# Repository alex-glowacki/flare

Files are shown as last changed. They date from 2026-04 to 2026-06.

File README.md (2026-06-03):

# FLARE
**Flight Lab for Avionics Research & Engineering**

A custom 450mm quadcopter with a DIY STM32H7-based flight controller and
ESP-NOW RC link. Built from scratch as a hands-on avionics and embedded
systems learning project.

---

## Project Status

| Phase | Goal | Status |
|---|---|---|
| 1 | STM32H7 bring-up — blink, UART, toolchain | ✅ Done |
| 2 | IMU bring-up — BMI323, sensor fusion | ✅ Done |
| 2.5 | Magnetometer — QMC5883P hard-iron calibration | ✅ Done |
| 3 | PID loop — stabilization, DSHOT motor output | ✅ Done |
| 4 | RC link — ESP-NOW, channel parsing, arming | ✅ Done |
| 4.5 | GPS — M100-5883 UBX binary parser, USART3 DMA | ✅ Done |
| 4.75  | SD card blackbox logger | ✅ Done |
| 5 | Remote firmware — sticks, OLED, switches | 🟡 In progress |
| 6 | Flight testing & PID tuning | 🟡 In progress |
| 7 | *(Future)* LiDAR mapping — RPLiDAR + Pi companion | 🔲 |

### Phase 6 — Flight Testing Detail

| Item | Status |
|---|---|
| First outdoor hover flight | ✅ Done (LOG000/LOG001) |
| IMU mounting offset calibration | ✅ Done — roll=+0.27°, pitch=−3.80°, bench-verified |
| Mag hard-iron calibration | ✅ Done — offset_x=−251.0, offset_y=+41.5 |
| SD blackbox logger operational | ✅ Done — LOG000–LOG008 captured |
| Yaw kd tuning — damping spin | ✅ Done — kd=0.05 confirmed (LOG001) |
| Yaw kp/output limit increase | ✅ Done — kp=1.2, out_limit=300 (LOG007) |
| Prop/motor direction verification | ✅ Done — all confirmed correct |
| Weak motor identification | ✅ Done — M1 (Front-Left, CCW) confirmed weaker than M3 via swap test |
| M1 motor replacement | 🔲 Pending — Readytosky 2212 920KV CCW needed |
| Software roll trim (interim) | 🔲 Pending — awaiting M1 swap back to original position |
| Stable hands-off hover | 🔲 Pending |
| ki_yaw = 0.01 | 🔲 Pending — after stable hover confirmed |

---

## Hardware

### Frame
- Custom PETG-CF printed, F450-class (450mm), self-modeled

### Flight Controller — FK723M1-ZGT6
- MCU: STM32H723ZGT6 (Cortex-M7, 192MHz)
- SPI1: PA5=SCK, PA6=MISO, PA7=MOSI
- I2C1: PB6=SCL, PB7=SDA
- CS (IMU): PB0
- INT1 (IMU): PB1
- USART1: PA9=TX, PA10=RX (debug / CP2102)
- USART2: PA2=TX, PA3=RX (ESP32 RC link)
- USART3: PB10=TX, PB11=RX (GPS)
- TIM4 DSHOT: PD12=M1, PD13=M2, PD14=M3, PD15=M4
- SD CS: PC0 (SPI1 shared with IMU)
- LED: PG7 (LED_USER)

### IMU — BMI323 (Arvian breakout, B0FG2ZFHNM)

| Wire color | Signal | Pin |
|---|---|-----|
| Orange | CSB | PB0 |
| Brown | SCX | PA5 |
| Blue | SDX | PA7 |
| Green | SDO | PA6 |
| Purple | INT1 | PB1 |
| White | VDD | 3V3 |
| Gray | GND | GND |

### GPS + Compass — HGLRC M100-5883

| M100-5883 Pin | FK723M1 Pin | Notes |
|---|---|---|
| 5V | PDB BEC 5V  | Do not use STM32 3.3V pin |
| GND | Common GND  | |
| TX | PB11 (USART3 RX) | GPS data → STM32 |
| RX | PB10 (USART3 TX) | Optional config commands |
| SDA | PB7 (I2C1 SDA) | QMC5883P compass |
| SCL | PB6 (I2C1 SCL) | QMC5883P compass |

- GPS chip: u-blox M10 (10th gen), 72 channels, GPS/GLONASS/BDS/Galileo/QZSS
- GPS protocol: UBX binary, NAV-PVT messages, 115200 baud, DMA ring buffer
- GPS fix confirmed indoors (8 satellites)
- Compass chip: QMC5883P, I2C address `0x2C`, chip ID `0x80`
- Hard-iron offsets: `offset_x = -251.0f`, `offset_y = 41.5f` (calibrated)
- Yaw stable at ~161–165° stationary

### ESCs — Readytosky 35A (×4)

| Motor | Position | Spin | Cap color | Pin  |
|---|---|---|---|---|
| M1 | Front-Left  | CCW  | Silver | PD12 |
| M2 | Front-Right | CW | Black | PD13 |
| M3 | Rear-Right  | CCW  | Silver | PD14 |
| M4 | Rear-Left | CW | Black | PD15 |

- Firmware: Bluejay (replaces stock BLHeli_S)
- Protocol: DSHOT300
- Props: 1045R on CCW motors (M1/M3), 1045L on CW motors (M2/M4)
- Demag Compensation: High (configured via BLHeliSuite + ATmega328P Nano)
- Config backed up: `config/esc_blheli_setup.ini`

> ⚠️ M1 (Front-Left, CCW, silver cap) is a known weak motor — produces less
> thrust than M3 at equivalent DSHOT values. Confirmed via motor swap test
> (LOG007/LOG008). Replacement Readytosky 2212 920KV CCW unit required.

### Power Distribution
- QWinOut PDB with built-in 5V and 12V BECs
- 3S LiPo with XT60
- 4S upgrade planned post stable-flight (verify PDB BEC supports up to 16.8V first)

### RC Link
- Nano ESP32 modules (ESP-NOW, quad-side and remote)
- Quad-side ESP32: **MAC `D4:E9:F4:E6:E9:90`**, GPIO17 (TX) → STM32 PA3 (USART2 RX)
- Remote ESP32: FrSky M7 Hall Sensor Gimbals (×2), 2-position toggle switches for arm/mode
- Shared GND between ESP32 and STM32

> ⚠️ Do not power the quad-side Nano ESP32 from the BEC 5V → VIN pin. The
> ESP32-S3 core requires 3.3V. Power from STM32 3.3V pin or a dedicated 3.3V
> regulator.

> ⚠️ Do not flash STM32 via ST-Link while the ESP32 shares the USB power rail.
> ST-Link reset glitches can corrupt ESP32 flash mid-write, changing the
> reported MAC address.

### FAA Remote ID
- Ruko R111S — hardware mount completed

### SD Card Blackbox Logger
- WWZMDiB micro-SD module, SPI1 shared with BMI323, CS=PC0
- FatFS, 5Hz write / 1Hz flush
- f_printf has no `%f` support — all floats scaled to integers permanently
- Column names encode scale factor (e.g. `roll_x100`, `lat_x1e6`)
- Last log: LOG008.CSV

### Remote Controller Hardware (Phase 5 — in progress)
- **Gimbals:** FrSky M7 Hall Sensor (×2) — analog, 4 axes total
- **OLED:** HiLetgo 2.42" SSD1309 128×64, SPI 7-pin
- **Switches:** 2-position toggle — arming (dedicated), mode angle/acro (dedicated)
- Pin assignments TBD pending wiring

### Debug / Programming
- ST-Link V2 clone (V2J37S7) — SWD, CLI only
- CP2102 USB-UART adapter — COM3, 115200 baud
  - CP2102 TX → PA10, RX → PA9, GND → GND, VCC unconnected

---

## Repository Structure

```
flare/
├── firmware/
│   ├── shared/                    # Shared headers (ESP32 + STM32)
│   │   └── flare_protocol.h       # RC packet definition, CRC-8/MAXIM
│   ├── fc/                        # STM32H7 flight controller firmware
│   │   ├── Core/
│   │   │   ├── Inc/
│   │   │   │   ├── main.h
│   │   │   │   ├── dshot.h        # DSHOT300 driver API
│   │   │   │   ├── imu_fusion.h   # Complementary filter API
│   │   │   │   ├── mag.h          # QMC5883P magnetometer driver API
│   │   │   │   ├── pid.h          # PID controller API
│   │   │   │   ├── flare.h        # Motor mixing, arming logic API
│   │   │   │   ├── rc.h           # USART2 RC receiver API
│   │   │   │   └── gps.h          # UBX binary GPS parser API
│   │   │   └── Src/
│   │   │       ├── main.c         # Boot sequence, 100Hz loop, UART output
│   │   │       ├── imu_fusion.c   # Complementary filter (roll, pitch, yaw)
│   │   │       ├── mag.c          # QMC5883P magnetometer driver
│   │   │       ├── dshot.c        # DSHOT300 direct DMA output
│   │   │       ├── pid.c          # PID controller
│   │   │       ├── flare.c        # Motor mixing, arming logic
│   │   │       ├── rc.c           # USART2 interrupt-driven RC receiver
│   │   │       ├── gps.c          # UBX NAV-PVT parser, USART3 DMA ring buffer
│   │   │       └── stm32h7xx_it.c # IRQ handlers (incl. DSHOT TC callback)
│   │   ├── cmake/stm32cubemx/     # CubeMX-generated CMake support
│   │   ├── CMakeLists.txt
│   │   └── build/Debug/           # Build output (gitignored)
│   ├── esp32_quad/                # ESP-NOW quad-side firmware (PlatformIO)
│   │   ├── src/main.cpp           # ESP-NOW RX → UART bridge to STM32 ✅ flashed
│   │   ├── extra_script.py        # SCons path injection for shared header
│   │   └── platformio.ini
│   └── esp32_remote/              # ESP-NOW remote firmware (PlatformIO)
│       ├── src/main.cpp           # 50Hz transmitter stub — pending wiring
│       ├── extra_script.py        # SCons path injection for shared header
│       └── platformio.ini
├── config/
│   └── esc_blheli_setup.ini       # BLHeli_S ESC configuration backup
└── docs/
    ├── README.md
    ├── architecture.md
    ├── hardware-notes.md
    └── session_summaries/         # Per-session progress logs
```

---

## Toolchain

| Tool | Version |
|---|---|
| arm-none-eabi-gcc | 15.2.1  |
| CMake | 4.3.1 |
| Ninja | 1.13.2  |
| STM32CubeProgrammer | v2.22.0 |
| VS Code + clangd | — |
| PlatformIO | — |

---

## Build & Flash

### STM32 (working directory: `firmware/fc`)

**Build:**
```powershell
cmake --build --preset Debug
```

**Flash:**
```powershell
& "C:\Program Files\STMicroelectronics\STM32Cube\STM32CubeProgrammer\bin\STM32_Programmer_CLI.exe" -c port=SWD freq=100 reset=HWrst -w build/Debug/fc.elf -rst
```

### ESP32 (working directory: `firmware/esp32_quad` or `firmware/esp32_remote`)

**Build:**
```powershell
C:\Users\alexg\.platformio\penv\Scripts\platformio.exe run --environment arduino_nano_esp32
```

**Flash** (double-tap RST first to enter DFU mode):
```powershell
C:\Users\alexg\.platformio\penv\Scripts\platformio.exe run --target upload --environment arduino_nano_esp32
```

**Serial monitor:**
```powershell
C:\Users\alexg\.platformio\penv\Scripts\platformio.exe device monitor --environment arduino_nano_esp32 --baud 115200
```

---

## Current PID Gains

| Axis  | kp  | ki  | kd | int_limit | out_limit |
|---|-----|-----|---|---|---|
| Roll  | 0.5 | 0.0 | 0.10 | 20.0 | 150.0 |
| Pitch | 0.5 | 0.0 | 0.10 | 20.0 | 150.0 |
| Yaw | 1.2 | 0.0 | 0.05 | 20.0 | 300.0 |

### Gain Tuning Decision Table

| Observation | Action |
|---|---|
| Yaw spin >500 °/s at hover throttle | Check motor torque balance — likely physical cause |
| Yaw drift ~1 °/s at hover | Add ki_yaw = 0.01 |
| Motors M1/M3 >> M2/M4 at hover | M1 weak — replace motor |
| Flip above ~43% throttle | Motor saturation + imbalance; do not push above 40% until M1 replaced |
| Roll/pitch oscillation after motor replacement | Re-evaluate kp; may need slight reduction |

---

## Magnetometer Notes

The QMC5883P on the HGLRC M100-5883 module is wired to I2C1 (PB6/PB7).

### Hard-iron calibration (completed)

```c
offset_x = -251.0f;
offset_y =   41.5f;
```

Applied in `main.c` before fusion. Yaw stable at ~161–165° stationary.

---

## RC Link — FLARE Protocol

### Packet format (`firmware/shared/flare_protocol.h`)

| Byte(s) | Field | Type | Notes |
|---|---|---|---|
| 0 | magic | uint8_t | `0xFA` — sync byte |
| 1–2 | throttle | uint16_t  | 1000–2000 (1000 = min) |
| 3–4 | roll | uint16_t  | 1000–2000 (1500 = center) |
| 5–6 | pitch | uint16_t  | 1000–2000 (1500 = center) |
| 7–8 | yaw | uint16_t  | 1000–2000 (1500 = center) |
| 9 | armed | uint8_t | 0 = disarmed, 1 = armed |
| 10 | mode | uint8_t | 0 = angle, 1 = acro |
| 11–12 | reserved | uint8_t[2]| Zero-padded, future use |
| 13 | checksum | uint8_t | XOR checksum over bytes [0–12] |

Total: **14 bytes**. Shared header used by both ESP32 and STM32 firmware.

### STM32 RC receiver (rc.c / rc.h)

- USART2, 115200 8N1, PA3 = RX
- Direct register RX: `SET_BIT(USART2->CR1, USART_CR1_RXNEIE_RXFNEIE)`
- Sync recovery: discards bytes until magic is seen
- XOR checksum validated on complete 14-byte frame
- `RC_GetPacket()` — returns new packet to main loop (clears flag)
- `RC_IsHealthy()` — returns 1 if packet received within `RC_TIMEOUT_MS` (250ms)
- USART2 IRQ priority: 8,0 (below DMA1_Stream0 at 0,0)

### ESP32 quad-side firmware (esp32_quad/src/main.cpp) ✅ flashed

- ESP-NOW receiver, Station mode
- MAC address: **`D4:E9:F4:E6:E9:90`** ← updated after reflash (flash corruption
  during ST-Link programming changed MAC from `D4:E9:F4:E8:10:74`)
- `on_packet_received()` callback: validates magic + length + checksum, forwards
  raw 14-byte packet over UART to STM32
- UART: GPIO17 (TX) → STM32 PA3, 115200 baud

### ESP32 remote-side firmware (esp32_remote/src/main.cpp) 🟡 built, pending wiring

- ESP-NOW transmitter targeting `D4:E9:F4:E6:E9:90`
- 100Hz transmit loop, ADC stick read, deadband, XOR checksum
- Pin assignments placeholders — update once hardware is wired
- Arming and mode via `INPUT_PULLUP` toggle switches

### Shared header path resolution (Windows PlatformIO)

Both ESP32 projects use `extra_script.py` (SCons pre-build hook) to inject
the absolute path to `firmware/shared/` into `CPPPATH`:

```python
shared_path = os.path.abspath(
    os.path.join(env["PROJECT_DIR"], "..", "shared")
)
env.Append(CPPPATH=[shared_path])
```

`platformio.ini` references it via `extra_scripts = pre:extra_script.py`.
Relative `build_flags = -I` paths do not resolve correctly on Windows.

---

## DSHOT300 Configuration

### Timing (@ 192MHz SYSCLK, TIM4 ARR = 639)

| Symbol | Value  | Meaning |
|---|---|---|
| Bit period | 3.33µs | 300 kbps |
| BIT_1 | 480 | 75% duty cycle — logic 1  |
| BIT_0 | 240 | 37.5% duty cycle — logic 0|
| Idle | 0 | 0% duty — idle-LOW (Bluejay) |

### Key implementation facts

- **No HAL DMA burst API** — `HAL_TIM_DMABurst_WriteStart` ignores NDTR on
  STM32H7 and runs continuously. Direct DMA register programming used instead.
- **TIM4->DCR:** DBA=13 (CCR1 offset), DBL=3 (4 transfers per burst)
- **Buffer:** `dshot_buf[17][4]` uint32_t at `0x24000000` (D1 AXI SRAM)
- **Idle-LOW:** `DSHOT_CCR_IDLE = 0` — required for Bluejay firmware
- **Bluejay CRC:** non-inverted: `(v ^ (v>>4) ^ (v>>8)) & 0x0F`
- **ESC keepalive:** `DSHOT_SendThrottle(0,0,0,0)` called every loop iteration
- **DMA1_Stream0 IRQ priority:** 0,0 (highest)

---

## Sensor Fusion

A complementary filter runs at 100Hz producing roll, pitch, and yaw in degrees.

### Algorithm

```
// Roll and pitch — accel reference (with mounting offsets applied)
roll_accel  = atan2(ay_g, az_g)  × (180/π) - IMU_ROLL_OFFSET
pitch_accel = atan2(-ax_g, az_g) × (180/π) - IMU_PITCH_OFFSET

// Gyro integration
roll_gyro  = roll_prev  + gx_dps × dt
pitch_gyro = pitch_prev + gy_dps × dt
yaw_gyro   = yaw_prev   + gz_dps × dt

// Complementary filter — roll and pitch
roll  = α × roll_gyro  + (1−α) × roll_accel
pitch = α × pitch_gyro + (1−α) × pitch_accel

// Yaw — gyro only until mag-fused yaw hold implemented
yaw = yaw_gyro   (drifts over time)
```

### Parameters

| Parameter | Value  | Notes |
|---|---|---|
| α (alpha) | 0.96 | Roll/pitch gyro weight |
| dt | 0.01s  | Matches 10ms loop tick |
| IMU_ROLL_OFFSET  | +0.27° | Bench-calibrated mounting offset |
| IMU_PITCH_OFFSET | −3.80° | Bench-calibrated mounting offset |
| ACC scale | `8.0 / 32768.0` g/LSB  | ±8g range |
| GYR scale | `2000.0 / 32768.0` dps/LSB | ±2000dps range |

---

## UART Serial Output Format

115200 baud, USART1 (CP2102 on COM3).

Boot messages:
```
[DSHOT] driver ready
[DSHOT] ESCs armed
[FLARE] boot ok
[IMU] WHO_AM_I    = 0x43 (expect 0x43)
[IMU] ACC default = 0x0028
[IMU] ACC write   = 0x4028 (expect 0x4028)
[IMU] GYR write   = 0x4048 (expect 0x4048)
[FUSION] complementary filter ready
[MAG] chip ID = 0x80
[MAG] QMC5883P ready
[FLARE] PID controller ready
[RC] init status=0 (0=OK)
[RC] USART2 receiver ready
[GPS] USART3 DMA receiver ready
[GPS] waiting for fix (may take 30-120s outdoors)...
[CAL] Hold still — levelling IMU (2s)...
[CAL] level offset: roll=X.XX  pitch=XX.XX
[IMU] starting 100Hz loop
```

100Hz data stream:
```
A:<ax> <ay> <az>  G:<gx> <gy> <gz>  R:<roll>  P:<pitch>  Y:<yaw>  RC:<OK|LOST>
```

1Hz GPS print:
```
[GPS] fix=<0|1> sats=<n> lat=<deg> lon=<deg> alt=<ft> spd=<mph>
```

---

## ST-Link V2 Clone Notes

Firmware: V2J37S7. Known limitations:
- GUI connection in STM32CubeProgrammer fails — use CLI only
- ITM SWO non-functional
- VS Code F5 flashing non-functional
- Always pass `freq=100 reset=HWrst` flags to CLI

**Memory read workaround** (when UART unavailable): promote variables to
`volatile` globals → find address with `arm-none-eabi-nm fc.elf | grep <symbol>`
→ read via STM32CubeProgrammer CLI `--upload` at the address.

---

## CubeMX Regeneration Warning

Regenerating code in CubeMX can:
- Wipe `#include` statements placed outside `USER CODE` blocks
- Introduce brace mismatches
- Move `/* USER CODE END WHILE */` outside the loop body
- Wipe MPU region config from `MPU_Config()` — always restore Region 1
  (AXI SRAM at `0x24000000`) after regen
- Wipe NVIC lines for USART2 — must be kept inside USER CODE blocks

Always inspect `main.c` after any CubeMX regeneration before building.

---

## Known Issues & Gotchas

- **SD/IMU SPI sharing:** SD writes on SPI1 can cause single-sample BMI323 accel
  dropouts. Mitigation: last-known-good accel guard in fusion loop.
- **f_printf float support:** FatFS `f_printf` has no `%f` — all floats scaled
  to integers permanently. Never attempt `%f` in log writes.
- **GPIO43/44 on Nano ESP32:** Must never be assigned to hardware UART — corrupts
  USB Serial/JTAG stack unrecoverably without chip erase.
- **ESC arming window:** DSHOT 0 frames must reach ESC within ~300ms of power-on.
  Arm immediately after `DSHOT_Init()`, before IMU init delays.
- **M1 motor weakness:** M1 (Front-Left, CCW) produces less thrust than M3 at
  equivalent DSHOT values. Causes persistent left roll bias under aerodynamic load.
  Replacement required before stable hover is achievable.

---

## Commit Convention

```
<type>(<scope>): <description>

Types:  feat, fix, tune, test, docs, refactor, chore
Scopes: fc/imu, fc/fusion, fc/mag, fc/pid, fc/dshot, fc/main, fc/rc, fc/gps,
        esp32/quad, esp32/remote, shared, docs, control
```

Examples:
```
feat(fc/gps): replace NEO-6M NMEA parser with UBX binary for M100-5883
fix(fc/imu): apply IMU mounting offset correction in complementary filter
tune(control): increase yaw kp and output limit for authority at hover
docs: update README for session 22 — flight testing progress
```

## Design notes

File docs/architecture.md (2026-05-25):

# FLARE — Architecture Overview

---

## System Block Diagram

```
[Hall Gimbals] ──► [ESP32 Remote]
                         │
                   ESP-NOW (2.4GHz)
                         │
                   [ESP32 Quad]
                         │
                   UART (115200)
                   GPIO17 → PA3
                         │
                  [STM32H723 FC]
                   ├── BMI323 IMU (SPI1)
                   ├── QMC5883L Mag (I2C1) ← onboard M100-5883, deferred
                   ├── DSHOT300 → ESC × 4
                   ├── M100-5883 GPS (USART3, UBX binary)
                   ├── SD Card Logger (SPI1 shared, planned)
                   └── Barometer (future)
```

---

## Component Responsibilities

| Component | Role |
|---|---|
| STM32H723ZGT6 | PID, sensor fusion, DSHOT motor output, RC packet parsing |
| BMI323 | 6-axis IMU (gyro + accel) over SPI1 |
| QMC5883L (M100-5883) | 3-axis magnetometer, yaw reference, over I2C1 — driver deferred  |
| HGLRC M100-5883 | GPS (u-blox M10, UBX NAV-PVT) + onboard QMC5883L compass |
| SD card module | SPI1 blackbox logger, CS on PC0 — planned Phase 5.5 |
| ESP32 (quad) | ESP-NOW receive → UART bridge to STM32 ✅ flashed & verified |
| ESP32 (remote) | Stick ADC read → ESP-NOW transmit, OLED display (Phase 5) |
| Readytosky 35A ESCs | Motor drive via DSHOT300, Bluejay firmware |

---

## Development Phases

| Phase | Goal | Status |
|---|---|---|
| 1 | STM32H7 bring-up — blink, UART, toolchain | ✅ Done |
| 2 | IMU bring-up — BMI323, sensor fusion | ✅ Done |
| 2.5 | Magnetometer — QMC5883P, yaw fusion | ✅ Done |
| 3 | PID loop — stabilization, DSHOT motor output | ✅ Done |
| 4 | RC link — ESP-NOW, channel parsing, arming | ✅ Done |
| 4.5 | GPS — M100-5883 UBX binary parser, USART3 DMA | ✅ Done |
| 5 | Remote firmware — sticks, OLED, switches | 🟡 In progress |
| 5.5 | SD card blackbox logger | 🟡 Planned |
| 6 | Flight testing & tuning | 🔲 |
| 7 | *(Future)* LiDAR mapping — RPLiDAR + Pi companion | 🔲 |

---

## Firmware Structure

```
firmware/
├── shared/                      # Headers shared between ESP32 and STM32
│   └── flare_protocol.h         # RC packet struct, XOR checksum, constants
├── fc/                          # STM32H723 flight controller
│   ├── Core/
│   │   ├── Inc/                 # Headers
│   │   │   ├── main.h
│   │   │   ├── dshot.h          # DSHOT300 driver API
│   │   │   ├── imu_fusion.h     # Complementary filter API
│   │   │   ├── mag.h            # QMC5883P driver API (retiring → QMC5883L)
│   │   │   ├── pid.h            # PID controller API
│   │   │   ├── flare.h          # Motor mixing, arming logic API
│   │   │   ├── rc.h             # USART2 RC receiver API
│   │   │   └── gps.h            # UBX binary GPS parser API
│   │   └── Src/
│   │       ├── main.c           # Boot sequence, 100Hz loop, UART output
│   │       ├── imu_fusion.c     # Complementary filter (roll, pitch, yaw)
│   │       ├── mag.c            # QMC5883P I2C driver (mag_ok=0 until replaced)
│   │       ├── dshot.c          # DSHOT300 direct DMA output (no HAL burst)
│   │       ├── pid.c            # PID controller
│   │       ├── flare.c          # Motor mixing, arming logic
│   │       ├── rc.c             # USART2 direct-register RC receiver
│   │       ├── gps.c            # UBX NAV-PVT parser, USART3 DMA ring buffer
│   │       ├── stm32h7xx_it.c   # IRQ handlers — DSHOT TC, USART2, USART3 DMA
│   │       ├── spi.c            # CubeMX SPI1 init
│   │       ├── i2c.c            # CubeMX I2C1 init
│   │       ├── usart.c          # CubeMX USART1 + USART2 + USART3 init
│   │       ├── gpio.c           # CubeMX GPIO init
│   │       └── ...
│   ├── cmake/stm32cubemx/       # CubeMX CMake integration
│   ├── CMakeLists.txt           # Includes firmware/shared via get_filename_component
│   ├── CMakePresets.json        # Debug preset — build/Debug/
│   ├── STM32H723XG_FLASH.ld    # Linker script — includes .AXI_SRAM section
│   ├── fc.ioc                   # CubeMX project file
│   └── .clangd                  # clangd config for VS Code IntelliSense
├── esp32_quad/                  # Quad-side ESP32 ✅ flashed & running
│   ├── src/main.cpp             # ESP-NOW RX → UART bridge to STM32
│   ├── extra_script.py          # SCons pre-build: injects firmware/shared into CPPPATH
│   └── platformio.ini
└── esp32_remote/                # Remote-side ESP32 🟡 built, pending wiring
    ├── src/main.cpp             # 100Hz ESP-NOW transmitter, stick/switch stubs
    ├── extra_script.py          # SCons pre-build: injects firmware/shared into CPPPATH
    └── platformio.ini
```

---

## FC Firmware Architecture (Phase 4.5 complete)

All flight controller application code lives in `firmware/fc/Core/Src/`.
Peripheral init (`spi.c`, `i2c.c`, `usart.c`, `gpio.c`) is CubeMX-generated
and must not be edited manually except inside `USER CODE` blocks.

**Key principle:** All user code must remain inside `/* USER CODE BEGIN */` /
`/* USER CODE END */` markers to survive CubeMX regeneration. Always inspect
`main.c` after regeneration — CubeMX can wipe the MPU config and the
`while(1)` closing brace.

### main.c Boot Sequence

```
MPU_Config()        — AXI SRAM non-cacheable (0x24000000, 512KB) for DMA buffers
MX_*_Init()         — CubeMX peripheral init (GPIO, DMA, UART1/2/3, SPI, TIM, I2C)
DSHOT_Init()        — configure DMA1_Stream0, set CCRs idle-LOW, start PWM
                      800 × 10ms = 8s of DSHOT 0 frames (Bluejay arm sequence)
BMI323_Init()       — SPI bring-up, feature engine, acc/gyr config
IMU_Fusion_Init()   — zero roll/pitch/yaw state
MAG_Init()          — I2C bring-up; sets mag_ok=0 if chip ID fails (expected
                      until QMC5883L driver replaces QMC5883P driver)
FLARE_Init()        — PID state, motor mixing init
RC_Init()           — arm USART2 RX via direct register write
GPS_Init()          — start USART3 DMA circular receive (512-byte ring buffer)
IMU calibration     — 200 samples × 10ms, average last 50 for level offsets

100Hz while loop:
  BMI323_ReadAccel / ReadGyro
  MAG_ReadHeading              — skipped if mag_ok == 0
  IMU_Fusion_Update            — complementary filter, all 3 axes
  GPS_Update()                 — scan DMA ring buffer, parse UBX NAV-PVT packets
  RC_GetPacket()               — consume validated RC packet if available
  if RC healthy and mode != SAFE:
    FLARE_Update               — PID + motor mixing
  else:
    FLARE disarmed, DSHOT 0 keepalive
  UART_Print                   — live telemetry including RC:OK/LOST
  every 100 loops (1s):
    [GPS] print — fix, sats, lat, lon, alt (ft), speed (mph)
    [DIAG] print — DMA send/tc counters
```

---

## FLARE RC Protocol

Defined in `firmware/shared/flare_protocol.h`.

### Packet Layout (14 bytes)

| Byte(s) | Field | Type | Notes |
|---|---|---|---|
| 0 | magic | uint8_t | `0xFA` |
| 1–2 | throttle | uint16_t | 1000–2000 |
| 3–4 | roll | uint16_t | 1000–2000, center 1500 |
| 5–6 | pitch | uint16_t | 1000–2000, center 1500 |
| 7–8 | yaw | uint16_t | 1000–2000, center 1500 |
| 9 | armed | uint8_t | 0 = disarmed, 1 = armed |
| 10 | mode | uint8_t | FLARE_MODE_* constants |
| 11–12 | reserved | uint8_t[2] | Zero-padded, reserved |
| 13 | checksum | uint8_t | XOR over bytes [0–12] |

### STM32 RC Receiver (rc.c)

- Direct register RX: `SET_BIT(USART2->CR1, USART_CR1_RXNEIE_RXFNEIE)`
- `USART2_IRQHandler` reads `USART2->RDR` directly, calls `RC_UART_RxCpltCallback()`
- Sync recovery: first byte must be `FLARE_PACKET_MAGIC` (`0xFA`)
- On full packet: validate magic + XOR checksum, copy to shadow buffer
- `RC_GetPacket()` — copies shadow buffer to caller, clears flag
- `RC_IsHealthy()` — returns 1 if last valid packet within `RC_TIMEOUT_MS (250)`

---

## GPS Driver (gps.c)

### Approach
Circular DMA receive into a 512-byte ring buffer in AXI SRAM (non-cacheable).
`GPS_Update()` is called each main loop iteration and walks new bytes from the
DMA write head through a UBX state machine. Complete, checksummed NAV-PVT
packets are parsed and used to update `GPS_Data_t`. No interrupts required
beyond DMA housekeeping.

### Protocol
UBX binary at 115200 baud, 10Hz. Single message type parsed:

| Message | Class | ID | Payload | Fields extracted |
|---|---|---|---|---|
| UBX-NAV-PVT | 0x01  | 0x07 | 92 bytes | fix_type, flags, numSV, lat, lon, hMSL, gSpeed, headMot |

### Checksum
Fletcher-8 over CLASS + ID + LEN + PAYLOAD (standard UBX). Packets with
invalid checksums are silently discarded and the state machine resets.

### Unit Conversions
- Latitude/longitude: raw × 1e-7 = decimal degrees
- Altitude: mm × 0.00328084 = feet MSL
- Speed: mm/s × 0.001 = m/s; m/s × 2.23694 = mph
- Heading: raw × 1e-5 = degrees true

### DMA Buffer Placement
```c
static uint8_t gps_dma_buf[512] __attribute__((section(".AXI_SRAM")));
```
Placed in RAM_D1 via the `.AXI_SRAM` linker section. The MPU non-cacheable
region at `0x24000000` ensures CPU reads are coherent with DMA writes.

---

## DSHOT300 Implementation

### Approach
Direct DMA register programming — HAL DMA burst API ignored NDTR on STM32H7.

### Buffer Layout
`dshot_buf[17][4]` — 17 rows × 4 motors, placed in AXI SRAM at `0x24000000`.
16 data rows (one bit per row) + 1 reset slot row (all zeros).

### Key Constants (@ 192MHz SYSCLK, ARR = 639)
| Symbol | Value | Meaning |
|---|---|---|
| `DSHOT_BIT_1` | 480 | 75% duty — logic 1 |
| `DSHOT_BIT_0` | 240 | 37.5% duty — logic 0 |
| `DSHOT_CCR_IDLE` | 0 | 0% duty — idle-LOW (Bluejay) |
| Bit period | 3.33µs | 300 kbps (DSHOT300) |

### Bluejay CRC
Non-inverted: `crc = (v ^ (v>>4) ^ (v>>8)) & 0x0F`
Standard DSHOT spec uses inverted CRC — Bluejay does not.

### IRQ Priorities
| Interrupt | Priority | Reason |
|---|---|---|
| DMA1_Stream0 (TC) | 0, 0 | Highest — idle-LOW restore is time-critical  |
| DMA1_Stream1 | 0, 0 | USART3 GPS DMA housekeeping |
| USART2 (RC RX) | 8, 0 | Must not preempt DSHOT TC handler |

---

## ESP32 Quad-Side Architecture ✅

### esp32_quad/src/main.cpp

```
setup():
  Serial.begin(115200)            — debug output
  Serial2.begin(115200, ...)      — UART bridge to STM32 (GPIO17 TX → PA3 RX)
  WiFi.mode(WIFI_STA), disconnect
  esp_now_init()
  esp_now_register_recv_cb(on_packet_received)

loop() at 1s:
  print rx_ok / rejected counters and last channel values

on_packet_received():
  validate magic + length + XOR checksum
  forward raw 14-byte packet over Serial2 to STM32
```

- MAC: `D4:E9:F4:E6:E9:90` (updated after flash corruption — was `D4:E9:F4:E8:10:74`)

---

## ESP32 Remote Firmware Architecture (Phase 5 — in progress)

### esp32_remote/src/main.cpp — 100Hz transmitter

```
setup():
  Serial.begin(115200)
  pinMode ARM_SWITCH, MODE_SWITCH → INPUT_PULLUP
  WiFi.mode(WIFI_STA), disconnect
  print own MAC address
  esp_now_init()
  esp_now_register_send_cb(on_packet_sent)
  esp_now_add_peer(kQuadMac)   ← D4:E9:F4:E6:E9:90

loop() at 100Hz:
  analogRead() × 4 axes → map_stick() → 1000–2000
  digitalRead() × 2 switches → armed / mode flags
  build FLARE_RC_Packet_t
  XOR checksum → pkt.checksum
  esp_now_send(kQuadMac, &pkt, 14)
```

### Pending Before Complete
- Wire M7 gimbals → assign GPIO ADC pins
- Wire arm + mode switches
- Measure per-axis ADC min/center/max
- Determine axis reversal per gimbal orientation
- Wire SSD1309 OLED (SPI) → add display driver

---

## SD Card Blackbox Logger (Phase 5.5 — planned)

### Approach
Share SPI1 with BMI323. Dedicated CS on PC0. Log telemetry string (same format
as UART output) to a `.txt` or `.csv` file on micro-SD each loop iteration or
at a configurable decimated rate.

### Key Constraints
- SD card SPI timing is much slower than BMI323 — ensure transactions never
  overlap (straightforward in single-threaded main loop)
- SD writes are blocking; consider write buffering if 100Hz loop timing is affected
- PC0 must be added as `GPIO_Output` (`SD_CS`) in CubeMX before firmware work

---

## Toolchain

| Tool | Version  | Purpose |
|---|---|---|
| STM32CubeMX | 6.17.0 | Peripheral config + code gen |
| arm-none-eabi-gcc | 15.2.1 | ARM cross-compiler |
| CMake | 4.3.1 | Build system |
| Ninja | 1.13.2 | Build backend |
| STM32CubeProgrammer | v2.22.0  | Flash + RAM read via ST-Link |
| VS Code + clangd | — | Editor + IntelliSense |
| PlatformIO | — | ESP32 build + flash |

### Build & Flash

```powershell
# STM32 — build (from firmware/fc/)
cmake --build --preset Debug

# STM32 — clean build
cmake --build --preset Debug --clean-first

# STM32 — flash
& "C:\Program Files\STMicroelectronics\STM32Cube\STM32CubeProgrammer\bin\STM32_Programmer_CLI.exe" `
  -c port=SWD freq=100 reset=HWrst -w build/Debug/fc.elf -rst

# STM32 — RAM read (for variable inspection without UART)
& "C:\Program Files\STMicroelectronics\STM32Cube\STM32CubeProgrammer\bin\STM32_Programmer_CLI.exe" `
  -c port=SWD freq=100 -r32 <address> <length>

# Find variable addresses
arm-none-eabi-nm build/Debug/fc.elf | Select-String "variable_name"

# ESP32 — build (from firmware/esp32_quad/ or esp32_remote/)
C:\Users\alexg\.platformio\penv\Scripts\platformio.exe run --environment arduino_nano_esp32

# ESP32 — flash (double-tap RST first)
C:\Users\alexg\.platformio\penv\Scripts\platformio.exe run --target upload --environment arduino_nano_esp32

# ESP32 — serial monitor
C:\Users\alexg\.platformio\penv\Scripts\platformio.exe device monitor --environment arduino_nano_esp32 --baud 115200
```

### CMake shared include path

```cmake
get_filename_component(SHARED_INC
    "${CMAKE_SOURCE_DIR}/../shared"
    ABSOLUTE
)
target_include_directories(${CMAKE_PROJECT_NAME} PRIVATE
    Core/Inc
    ${SHARED_INC}
)
```

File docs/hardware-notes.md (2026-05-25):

# FLARE — Hardware Notes

---

## STM32H723ZGT6 (FK723M1 board)

- Cortex-M7 @ 192MHz SYSCLK (HSI PLL: PLLM=4, PLLN=12, PLLP=1)
- 1MB Flash, 564KB RAM, 144-pin LQFP
- **Clone ST-Link V2 (V2J37S7):** GUI connection in CubeProgrammer fails — use
  CLI only with `freq=100 reset=HWrst` flags. ITM SWO non-functional.

### Pin Assignments

| Function | Pin | Notes |
|---|---|---|
| SPI1 SCK | PA5 | BMI323 + SD card (shared bus) |
| SPI1 MISO | PA6 | BMI323 + SD card (shared bus) |
| SPI1 MOSI | PA7 | BMI323 + SD card (shared bus) |
| IMU CS | PB0 | Active-low, manual GPIO |
| IMU INT1 | PB1 | Not yet used |
| SD CS | PC0 | Planned — GPIO output, to be added in CubeMX |
| I2C1 SCL | PB6 | QMC5883L compass (M100-5883, deferred) |
| I2C1 SDA | PB7 | QMC5883L compass (M100-5883, deferred) |
| USART1 TX | PA9 | CP2102 RX (debug) |
| USART1 RX | PA10 | CP2102 TX (debug) |
| USART2 TX | PA2 | ESP32 quad-side UART RX (unused in Phase 4)  |
| USART2 RX | PA3 | ESP32 quad-side UART TX |
| USART3 TX | PB10 | GPS M100-5883 RX (config, optional) |
| USART3 RX | PB11 | GPS M100-5883 TX |
| User LED | PG7 (LED_USER) | |
| TIM4 CH1 | PD12 | DSHOT M1 (Front-Left) |
| TIM4 CH2 | PD13 | DSHOT M2 (Front-Right) |
| TIM4 CH3 | PD14 | DSHOT M3 (Rear-Right) |
| TIM4 CH4 | PD15 | DSHOT M4 (Rear-Left) |

> **Not broken out (do not use):** PA13, PA14 (SWD), PC14, PC15 (oscillator),
> PH0, PH1 (oscillator).

### CubeMX SPI1 Configuration (confirmed working)

```c
hspi1.Init.Mode                    = SPI_MODE_MASTER;
hspi1.Init.Direction               = SPI_DIRECTION_2LINES;
hspi1.Init.DataSize                = SPI_DATASIZE_8BIT;
hspi1.Init.CLKPolarity             = SPI_POLARITY_LOW;
hspi1.Init.CLKPhase                = SPI_PHASE_1EDGE;
hspi1.Init.NSS                     = SPI_NSS_SOFT;
hspi1.Init.BaudRatePrescaler       = SPI_BAUDRATEPRESCALER_16;  /* 6 MHz */
hspi1.Init.FirstBit                = SPI_FIRSTBIT_MSB;
hspi1.Init.NSSPMode                = SPI_NSS_PULSE_DISABLE;
hspi1.Init.FifoThreshold           = SPI_FIFO_THRESHOLD_01DATA;
hspi1.Init.MasterKeepIOState       = SPI_MASTER_KEEP_IO_STATE_ENABLE;
hspi1.Init.MasterInterDataIdleness = SPI_MASTER_INTERDATA_IDLENESS_00CYCLE;
```

### CubeMX I2C1 Configuration (confirmed working)

- Speed Mode: Fast Mode
- Clock Speed: 400000 Hz (400 kHz)
- Pins: PB6 = SCL (AF4), PB7 = SDA (AF4)

### CubeMX USART1 Configuration (debug)

- 115200 baud, 8N1, TX/RX mode
- PA9 = TX (AF7), PA10 = RX (AF7)
- No interrupt — polling TX via `HAL_UART_Transmit(..., HAL_MAX_DELAY)`

### CubeMX USART2 Configuration (ESP32 RC link)

- 115200 baud, 8N1, TX/RX mode
- PA2 = TX (AF7), PA3 = RX (AF7)
- **NVIC interrupt enabled**, priority **8, 0**
- Direct register RX: `SET_BIT(USART2->CR1, USART_CR1_RXNEIE_RXFNEIE)` armed
  from `RC_Init()` — bypasses `HAL_UART_Receive_IT` which hangs on STM32H7
- `USART2_IRQHandler` in `stm32h7xx_it.c` reads `USART2->RDR` directly and
  calls `RC_UART_RxCpltCallback()`

### CubeMX USART3 Configuration (GPS)

- **115200 baud**, 8N1, TX/RX mode
- PB10 = TX (AF7), PB11 = RX (AF7)
- DMA: DMA1_Stream1, USART3_RX request, Peripheral→Memory, byte width,
  **Circular mode** — continuous ring buffer receive
- NVIC interrupt enabled (for HAL DMA housekeeping)
- `GPS_Init()` starts DMA via `HAL_UART_Receive_DMA(&huart3, buf, 512)`
- `GPS_Update()` polls DMA write head via NDTR each loop iteration

### CubeMX TIM4 Configuration (DSHOT300)

- Prescaler: 0 (no division)
- Counter Period (ARR): 639
- Clock Division: DIV1
- Auto-Reload Preload: Enabled
- PWM Mode 1 on CH1–CH4 (PD12–PD15, AF2)
- DMA: DMA1_Stream0, TIM4_UP request, Memory→Peripheral, word width, Normal mode
- `DSHOT_CCR_IDLE = 0` — outputs held idle-LOW between frames (Bluejay requirement)

### STM32H7 SPI Gotchas

- **NSSP Mode** must be disabled and **MasterKeepIOState** must be enabled —
  otherwise the peripheral pulses CS between bytes even with manual CS control.
- **3-byte transactions are unreliable.** The STM32H7 SPI peripheral drops the
  3rd byte on 3-byte transfers regardless of approach. Always use 4-byte
  transactions padded with a dummy byte.
- **RX FIFO does not drain on CS de-assert.** Call `SPI1_FlushRxFifo()`
  (disable + re-enable peripheral) between transactions to prevent stale data.
- **Soft reset mid-transaction** leaves the peripheral in an undefined state.
  Follow with `HAL_SPI_DeInit()` + `MX_SPI1_Init()` to recover cleanly.

### STM32H7 DMA / DSHOT Gotchas

- **`HAL_TIM_DMABurst_WriteStart` ignores NDTR** on STM32H7 HAL and runs
  continuously regardless of Normal mode setting. Do not use it for DSHOT.
  Use direct DMA register programming instead.
- **DSHOT idle-LOW required for Bluejay.** `DSHOT_CCR_IDLE` must be 0, not
  ARR+1. Bluejay's stricter state machine rejects all frames when idle is HIGH.
  BLHeli_S tolerates idle-HIGH but pulses/gallops; Bluejay produces silence.
- **CCR must be forced idle-LOW after each frame.** Set `CCR1–CCR4 = 0` in the
  DMA transfer-complete ISR to restore idle-LOW between frames.
- **Do not force-abort DMA mid-transfer.** `DSHOT_StartDMA()` must wait for the
  previous stream to be disabled (EN bit cleared by TC handler) before
  re-arming.
- **IRQ priority:** DMA1_Stream0 must be at higher priority than USART2.
  Use 0,0 for DMA1_Stream0 and 8,0 for USART2.

### STM32H7 UART Gotcha — HAL_UART_Receive_IT hangs

`HAL_UART_Receive_IT` hangs on STM32H7 HAL when called after peripheral init
in certain FIFO/lock states. Workaround for USART2 RC receiver:

1. Unlock handle: `__HAL_UNLOCK(&huart2)`
2. Clear error flags: `__HAL_UART_CLEAR_FLAG(...)`
3. Force state: `huart2.gState = HAL_UART_STATE_READY`
4. Arm RX directly: `SET_BIT(USART2->CR1, USART_CR1_RXNEIE_RXFNEIE)`
5. Handle in `USART2_IRQHandler` by reading `USART2->RDR` directly

### CubeMX Regeneration Gotchas

- **MPU_Config() gets wiped.** CubeMX regeneration replaces the custom
  MPU config with a default 4GB no-access region. The AXI SRAM non-cacheable
  region (Region 0, `0x24000000`, 512KB, TEX=1 C=0 B=0) required for DMA
  buffers must be manually restored after every regen.
- **USER CODE blocks:** All user code must be inside `/* USER CODE BEGIN */` /
  `/* USER CODE END */` markers. Includes, defines, and callbacks placed outside
  are silently wiped on regen.
- **`while(1)` closing brace** can be lost on regen — always verify `main.c`
  compiles cleanly after regeneration.

### Linker Script

File: `STM32H723XG_FLASH.ld`

A custom `.AXI_SRAM` output section was added to place DMA buffers in the
non-cacheable RAM_D1 region:

```ld
.AXI_SRAM (NOLOAD) :
{
  . = ALIGN(4);
  *(.AXI_SRAM)
  *(.AXI_SRAM*)
  . = ALIGN(4);
} >RAM_D1
```

Any buffer shared between CPU and DMA should use:
```c
__attribute__((section(".AXI_SRAM")))
```

---

## BMI323 IMU (Arvian Breakout Board — Amazon B0FG2ZFHNM)

- **Interface:** SPI (Mode 0, MSB first, up to 10 MHz — using 6 MHz)
- **VCC:** 3.3V — do NOT connect to 5V
- **CS:** Active-low, driven manually via GPIO

### Wiring (Arvian → FK723M1)

| Wire Color | Arvian Label | FK723M1 Pin |
|---|---|---|
| Orange | CSB | PB0 |
| Brown | SCX | PA5 (SCK) |
| Blue | SDX | PA7 (MOSI)  |
| Green | SDO | PA6 (MISO)  |
| Purple | INT1 | PB1 |
| White | VDD | 3V3 |
| Gray | GND | GND |

### SPI Protocol

**Read (4 bytes total):**
```
TX: [addr | 0x80]  [0x00 dummy]  [0x00]  [0x00]
RX: [ignored]      [ignored]     [LSB]   [MSB]
```

**Write (4 bytes total):**
```
TX: [addr & 0x7F]  [data_LSB]  [data_MSB]  [0x00 dummy]
```

Use `HAL_SPI_TransmitReceive` for both reads and writes — `HAL_SPI_Transmit`
truncates multi-byte writes on STM32H7.

### Confirmed Register Values

| Register | Address | Value Written | Expected | Meaning |
|---|---|---|---|---|
| WHO_AM_I | 0x00 | — | 0x43 | Chip ID |
| ACC_CONF | 0x20 | 0x4028 | 0x4028 | 100Hz, ±8g, cont. |
| GYR_CONF | 0x21 | 0x4048 | 0x4048 | 100Hz, ±2000dps, cont.|

---

## HGLRC M100-5883 GPS + Compass Module

Replaces both the GY-NEO6MV2 (NEO-6M) GPS and the GY-271 (QMC5883P) magnetometer.

### Specs

| Spec | Value |
|---|---|
| GPS chip | u-blox M10 (10th gen) |
| Channels | 72 |
| Constellations | GPS, GLONASS, BDS, Galileo, QZSS |
| Update rate | 10 Hz |
| Baud rate | 115200 (default) |
| Protocol | UBX binary |
| Compass chip | QMC5883L |
| Compass interface | I2C, address `0x0D` |
| Size / weight | 21×21×8 mm / 7.73 g |
| Power | 3.3–5V (power from 5V BEC — some units need ≥3.7V) |

### Wiring (M100-5883 → FK723M1)

| M100-5883 Pin | FK723M1 Pin | Notes |
|---|---|---|
| 5V | PDB BEC 5V rail  | Never from STM32 3.3V pin |
| GND | Common GND | |
| TX | PB11 (USART3 RX) | GPS data → STM32 |
| RX | PB10 (USART3 TX) | Optional config commands |
| SDA | PB7 (I2C1 SDA) | QMC5883L — leave unsoldered for now |
| SCL | PB6 (I2C1 SCL) | QMC5883L — leave unsoldered for now |

### UBX NAV-PVT Fields Used

| Offset | Field | Unit | Converted to |
|---|---|---|---|
| 20 | fixType  | — | fix_type (0–5) |
| 21 | flags | — | fix_valid (bit 0)  |
| 23 | numSV | count | satellites |
| 24 | lon | deg×1e-7 | longitude (float)  |
| 28 | lat | deg×1e-7 | latitude (float) |
| 36 | hMSL | mm | altitude_ft |
| 60 | gSpeed | mm/s | speed_ms, speed_mph|
| 64 | headMot  | deg×1e-5 | course_deg |

### GPS Driver Notes

- DMA buffer: 512 bytes in `.AXI_SRAM` (non-cacheable)
- Parser: UBX state machine in `gps.c`, no NMEA parsing
- Requires valid 3D fix (`fixType >= 3` AND `flags & 0x01`) before populating data
- Cold start: 30–120 seconds outdoors; will not fix indoors

### QMC5883L Compass (Deferred)

- I2C address: `0x0D`
- Different chip and register map from the retired QMC5883P (GY-271)
- Driver to be written once GPS is verified working and SDA/SCL are soldered
- Will replace `mag.c` (currently QMC5883P driver, returning `mag_ok=0`)

---

## Nano ESP32 (Quad-side) ✅ Flashed & Running

- **Role:** ESP-NOW receiver → UART bridge to STM32
- **MAC address: `D4:E9:F4:E6:E9:90`** ← current MAC after reflash
  - Previous MAC was `D4:E9:F4:E8:10:74` — changed after flash corruption
    caused by ST-Link reset glitching the shared USB rail during STM32 flash
- **UART wiring:**

| ESP32 Pin | Direction | STM32 Pin |
|---|---|---|
| GPIO17 / A0 (TX) | → | PA3 (USART2 RX) |
| GND | shared | GND |

- GPIO18 (RX) wired to PA2 (USART2 TX) but unused in Phase 4
- Boot output confirms MAC address, ESP-NOW ready, diagnostic loop

> ⚠️ **Power:** Do not feed BEC 5V into Nano VIN. The ESP32-S3 requires 3.3V.
> Power from STM32 3.3V pin or a dedicated 3.3V regulator. The Nano may appear
> powered via VIN (LED on) but ESP-NOW will not function correctly.

> ⚠️ **Flash corruption risk:** Do not flash STM32 via ST-Link while the
> ESP32 is powered from the shared USB rail. ST-Link reset can corrupt ESP32
> flash mid-write, which silently changes the reported MAC address. Always
> disconnect or power-cycle the ESP32 before ST-Link flashing.

### Windows DFU Flash Note

First flash on a new Windows machine requires installing the Nano ESP32 board
package through Arduino IDE once — this provisions the WinUSB DFU driver that
PlatformIO's `dfu-util` needs. After that initial install, PlatformIO uploads
work standalone without Arduino IDE.

To enter DFU mode: double-tap the RST button. The RGB LED changes to indicate
DFU mode. Then immediately run the PlatformIO upload command.

---

## Nano ESP32 (Remote-side) 🟡 Firmware Built — Pending Wiring

- **Role:** Read M7 hall sensor gimbals + switches → transmit FLARE_RC_Packet_t
  to quad ESP32 via ESP-NOW at 100Hz
- **Target peer MAC:** `D4:E9:F4:E6:E9:90` (hardcoded in firmware as `kQuadMac`)
- **Pin assignments:** TBD — update `firmware/esp32_remote/src/main.cpp` once wired

### Planned Hardware

| Component | Part | Notes |
|---|---|---|
| Gimbals | FrSky M7 Hall Sensor (×2) | Analog output, 4 axes, 0–3.3V  |
| OLED | HiLetgo 2.42" SSD1309 128×64 SPI | Use SPI 7-pin variant |
| Arm switch  | 2-position ON-ON toggle | INPUT_PULLUP, LOW = armed |
| Mode switch | 2-position ON-ON toggle | INPUT_PULLUP, LOW = acro |

### ADC Calibration (TBD after wiring)

```cpp
#define ADC_MIN      100    // measure at stick minimum
#define ADC_MAX      4000   // measure at stick maximum
#define ADC_DEADBAND 40     // raw counts either side of center
```

---

## SD Card Blackbox Logger (Planned — Phase 5.5)

- **Module:** Standard SPI micro-SD breakout, 3.3V (level-shifted)
- **Bus:** Shared SPI1 with BMI323 (PA5 SCK, PA6 MISO, PA7 MOSI)
- **CS:** PC0 — dedicated GPIO output (to be added in CubeMX)
- **Logs:** UART telemetry stream to `.txt` or `.csv` on SD card

### Wiring (SD module → FK723M1)

| SD Pin | FK723M1 Pin | Notes |
|---|---|---|
| VCC | 3.3V | |
| GND | Common GND  | |
| SCK | PA5 | Shared with BMI323  |
| MOSI | PA7 | Shared with BMI323  |
| MISO | PA6 | Shared with BMI323  |
| CS | PC0 | Dedicated |

### CubeMX Changes Required

1. Add `PC0` as `GPIO_Output`, label `SD_CS`
2. No changes to SPI1 — configuration unchanged
3. Regenerate and audit `main.c` closing brace as always

---

## ESCs — Readytosky 35A BLHeli_S + Bluejay Firmware

- Signal wire: White
- Ground wire: Black
- **Firmware: Bluejay** (replaces stock BLHeli_S)
- Motor mapping (X-frame convention):

| Motor | Position | Spin | DSHOT Pin |
|---|---|---|---|
| M1 | Front-Left  | CCW  | PD12 |
| M2 | Front-Right | CW | PD13 |
| M3 | Rear-Right  | CCW  | PD14 |
| M4 | Rear-Left | CW | PD15 |

### Bluejay-Specific Notes

- **CRC is non-inverted:** `(v ^ v>>4 ^ v>>8) & 0xF` — opposite of the
  published DSHOT spec (`~(v ^ v>>4 ^ v>>8) & 0xF`). FLARE firmware uses
  non-inverted CRC to match Bluejay.
- **Idle state must be LOW.** Bluejay's stricter frame sync rejects all frames
  if the signal idles HIGH between frames. `DSHOT_CCR_IDLE = 0`.
- **Telemetry bit:** kept at 0 — bidirectional DSHOT not enabled.
- **DSHOT throttle range:** 48 (minimum) to 2047 (maximum). Values 1–47 are
  reserved special commands. 0 = disarm/stop.

### BLHeliSuite 4-Way Interface Setup

- Arduino Nano (ATmega328P) flashed with 4-way interface firmware
- **Baud: 115200** (default does not work — must select 115200 explicitly)
- LGT8F328P clones fail the 4-way-if handshake — must use genuine ATmega328P
- Nano COM port: COM11
- FC/debug COM port: COM3 (CP2102)

---

## CP2102 USB-UART Adapter

| CP2102 | FK723M1 |
|---|---|
| TX | PA10 (USART1 RX) |
| RX | PA9  (USART1 TX) |
| GND | GND |
| VCC | unconnected |

- COM port: COM3
- Baud: 115200 8N1

> ⚠️ Do not connect an explicit GND wire from CP2102 to STM32 if it could land
> on the RESET pin — shared ground is provided via USB to PC. A GND wire on
> RESET causes hard faults.

---

## General Notes

- **Soft-mount the FC stack.** Motor vibration aliasing into the IMU is the
  primary cause of PID instability in DIY flight controllers. Use silicone
  grommets or O-ring standoffs — never hard-mount.
- **3.3V logic throughout.** BMI323, QMC5883L, GPS TX, ESP32 UART, and
  STM32H7 GPIO are all 3.3V compatible. Do not expose any signal line to 5V.
- **GPS power:** Power GPS from 5V BEC, not the FC 3.3V rail.
- **Magnetometer placement:** Mount the M100-5883 away from motors, ESCs, and
  power wires. Calibrate QMC5883L after final mounting position is fixed.
- **ESC keepalive:** Bluejay disarms if no valid DSHOT frame is received for
  ~250ms. The main loop sends DSHOT 0 every iteration as a keepalive.
- **STM32 power during ESC work:** Power the STM32 via PDB 5V BEC (not USB-C)
  whenever ESCs are powered — both must share a common ground reference.
- **Do not flash STM32 via ST-Link while ESP32 shares USB power rail.** ST-Link
  reset can glitch the 3.3V rail and corrupt ESP32 flash mid-write, silently
  changing the Nano's reported MAC address.
- **Loose connections:** Dupont/header pin connections can work loose between
  sessions. If previously working hardware stops working, reseat all connectors
  before troubleshooting firmware.

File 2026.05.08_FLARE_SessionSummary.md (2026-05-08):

# FLARE Motor Debug Session — 2026-05-08

## Problem
Motors pulse/stutter randomly; spin direction inconsistent.

## Root Causes Found and Fixed

### 1. Throttle mapping floor too high (`main.c`)
RC minimum (1000) was mapping to DSHOT 1200 instead of DSHOT 48, causing motors to immediately blast at ~58% power when armed.

**Fixed to:**
```c
uint16_t dshot_thr = (uint16_t)(((float)(rc_pkt.throttle - 1000) / 1000.0f) * (2047.0f - 48.0f) + 48.0f);
```

### 2. PID engage threshold wrong (`flare.c`)
Threshold of `1300` was 62% of the corrected DSHOT range, meaning PID stabilisation never engaged during normal flight.

**Fixed to:** `if (state.throttle < 250)` (~10% above DSHOT minimum)

### 3. Arm switch inverted (`esp32_remote/src/main.cpp`)
`INPUT_PULLUP` with `== HIGH` meant the FC was always commanded ARMED when the switch was off.

**Fixed to:**
```cpp
pkt.armed = (digitalRead(PIN_ARM_SWITCH) == LOW) ? FLARE_ARMED : FLARE_DISARMED;
```

### 4. Excessive blocking UART in main loop (`main.c`)
~35ms of `HAL_UART_Transmit` per iteration was dropping the effective control rate from 100Hz to ~22Hz. Removed all `[DEBUG]` prints and the `[RC] bytes=...` diagnostic line. One `[THR]` print remains per armed iteration.

## Files Changed
- `firmware/fc/Core/Src/main.c`
- `firmware/fc/Core/Src/flare.c`
- `firmware/esp32_remote/src/main.cpp`
- `CLAUDE.md` (updated with firmware invariants)

## Still Outstanding

### Motor direction
All 4 ESCs have `Eep_Pgm_Direction=1` (same direction). Need to verify with props off — M1/M3 should spin CCW, M2/M4 CW. Fix via:
- Physical wire swap on CW motors (swap any two of three phase wires on M2 and M4), OR
- Set `Eep_Pgm_Direction=2` for ESC2/ESC4 in BLHeliSuite and reflash those ESCs

### Throttle calibration verification
Throttle stick center sits at ~43% on the OLED. Need to push stick to physical bottom stop and confirm display reads ~0%. If it reads significantly above 0%, `kThrottle.min = 265` in `esp32_remote/src/main.cpp` needs updating to the actual ADC floor on pin A1.

### Magnetometer calibration
Yaw drifts ~65 dps when motors run due to EMI corrupting the QMC5883P. Hard-iron offsets (`mag_cal.offset_x/y` in `main.c`) are currently zero. Needs calibration before flight; consider physically separating the magnetometer from power leads and ESC wiring.

## Next Test Procedure
1. Flash both FC firmware and remote firmware
2. Arm switch OFF
3. Throttle stick to physical bottom stop
4. Verify OLED shows ~0% throttle
5. Flip arm switch ON
6. Slowly raise throttle — motors should spin up smoothly from idle
7. Confirm M1/M3 spin CCW and M2/M4 spin CW (props off)

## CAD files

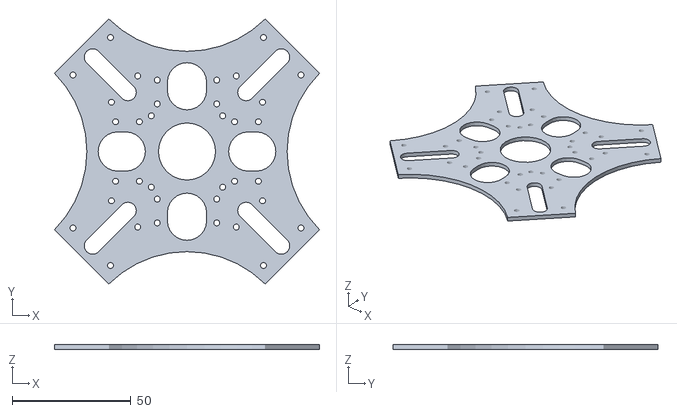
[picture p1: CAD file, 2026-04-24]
hardware/frame/2605-36477_MDL_top-mount.stl
111.4 x 111.4 x 2.00

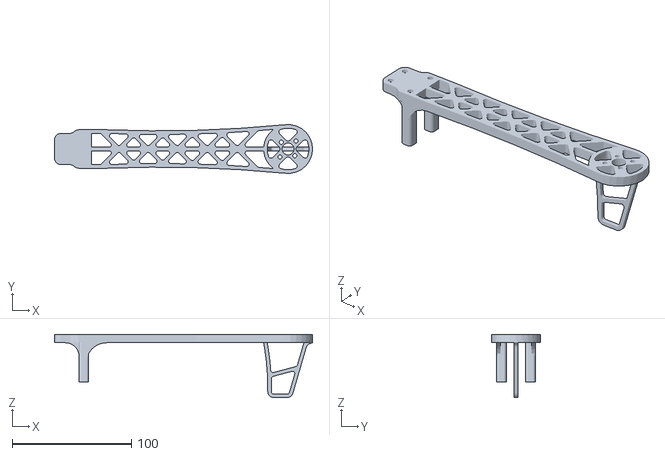
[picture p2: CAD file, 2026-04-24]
hardware/frame/2605-36477_MDL_arm.stl
216.2 x 40.8 x 53.0

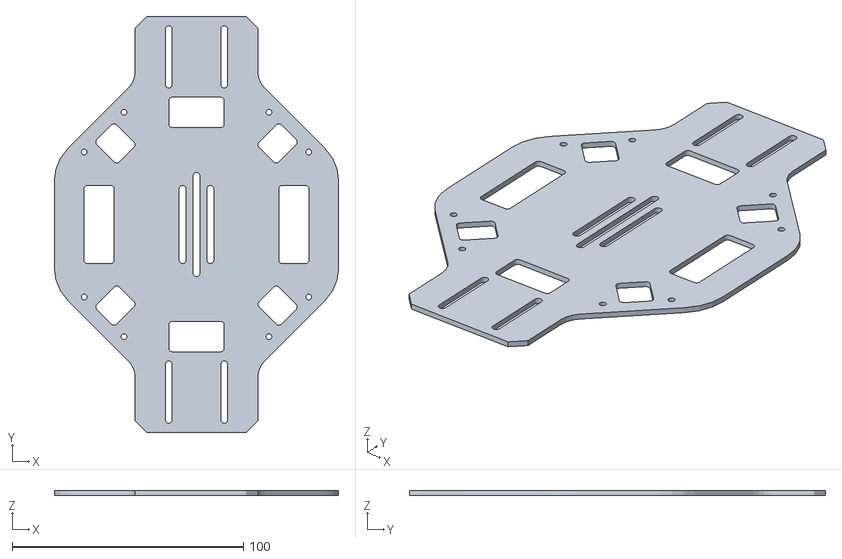
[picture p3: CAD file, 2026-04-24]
hardware/frame/2605-36477_MDL_bottom-mount.stl
123.1 x 180.0 x 2.00

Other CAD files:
hardware/frame/2605-36477_MDL_arm.dwg
hardware/frame/2605-36477_MDL_bottom-mount.dwg
hardware/frame/2605-36477_MDL_top-mount.dwg

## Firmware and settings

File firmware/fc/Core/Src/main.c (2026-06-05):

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
/* Includes ------------------------------------------------------------------*/
#include "main.h"
#include "dma.h"
#include "i2c.h"
#include "spi.h"
#include "tim.h"
#include "usart.h"
#include "gpio.h"
#include "fatfs.h"

/* USER CODE BEGIN Includes */
#include "math.h"
#include "dshot.h"
#include "flare.h"
#include "flare_protocol.h"
#include "gps.h"
#include "imu_fusion.h"
#include "mag.h"
#include "rc.h"
#include "sd.h"
#include <stdint.h>
#include <stdio.h>
#include <string.h>
/* USER CODE END Includes */

/* USER CODE BEGIN PD */

/* ── BMI323 register addresses ──────────────────────────────────────────── */
#define BMI323_REG_CHIP_ID       0x00
#define BMI323_REG_ACC_DATA      0x03
#define BMI323_REG_GYR_DATA      0x06
#define BMI323_REG_ACC_CONF      0x20
#define BMI323_REG_GYR_CONF      0x21
#define BMI323_REG_CMD           0x7E
#define BMI323_REG_FEATURE_IO0   0x10
#define BMI323_REG_FEATURE_IO1   0x11
#define BMI323_REG_FEATURE_IO2   0x12
#define BMI323_REG_FEATURE_IO_ST 0x14
#define BMI323_REG_FEATURE_CTRL  0x40

/* ── BMI323 configuration values ────────────────────────────────────────── */
#define BMI323_CMD_SOFT_RESET    0xDEAF
#define BMI323_ACC_CONF_VAL      0x4028
#define BMI323_GYR_CONF_VAL      0x4048

/* Loop interval — 10ms = 100Hz */
#define IMU_LOOP_INTERVAL_MS     10

/* ── IMU level calibration ───────────────────────────────────────────────── */
#define IMU_CAL_SAMPLES          1000    /* 10s at 10ms/sample                 */
#define IMU_CAL_SETTLE           900     /* discard first 9s, average last 1s */
#define IMU_CAL_AVG_COUNT        (IMU_CAL_SAMPLES - IMU_CAL_SETTLE) /* 100  */
#define IMU_CAL_MAX_OFFSET_DEG   10.0f  /* sanity limit — halt if exceeded   */

/* USER CODE END PD */

/* USER CODE BEGIN PM */

#define BMI323_POST_WRITE_DELAY()                                              \
  do {                                                                         \
    for (int _d = 0; _d < 200; _d++) {                                         \
      __NOP();                                                                 \
    }                                                                          \
  } while (0)

/* USER CODE END PM */


/* USER CODE BEGIN PV */

extern volatile uint32_t dshot_send_count;
extern volatile uint32_t dshot_tc_count;

volatile uint16_t who_am_i_result   = 0;
volatile uint16_t acc_conf_readback = 0;
volatile uint16_t gyr_conf_readback = 0;
volatile uint16_t acc_conf_default  = 0;

volatile int16_t imu_acc_x = 0;
volatile int16_t imu_acc_y = 0;
volatile int16_t imu_acc_z = 0;

volatile int16_t imu_gyr_x = 0;
volatile int16_t imu_gyr_y = 0;
volatile int16_t imu_gyr_z = 0;

/* Last known-good accel samples — used to replace all-zero dropout reads */
static int16_t last_acc_x = 0;
static int16_t last_acc_y = 0;
static int16_t last_acc_z = 0;

IMU_Fusion_t imu_fusion;

MAG_Cal_t mag_cal;  /* hard-iron offsets — zero until calibrated */
float mag_heading;  /* degrees [0, 360), updated each loop       */

static FLARE_RC_Packet_t rc_pkt = {0};  /* persists across loop iterations */

GPS_Data_t gps_data;  /* latest parsed GPS fix, updated each loop */

/* USER CODE END PV */

void SystemClock_Config(void);
static void MPU_Config(void);
/* USER CODE BEGIN 0 */

static void UART_Print(const char *s)
{
    HAL_UART_Transmit(&huart1, (const uint8_t *)s, strlen(s), HAL_MAX_DELAY);
}

static void SPI1_FlushRxFifo(void)
{
    __HAL_SPI_DISABLE(&hspi1);
    __HAL_SPI_ENABLE(&hspi1);
}

static uint16_t BMI323_ReadReg(uint8_t reg)
{
    uint8_t tx[4] = {reg | 0x80, 0x00, 0x00, 0x00};
    uint8_t rx[4] = {0x00, 0x00, 0x00, 0x00};
    SPI1_FlushRxFifo();
    HAL_GPIO_WritePin(IMU_CS_GPIO_Port, IMU_CS_Pin, GPIO_PIN_RESET);
    (void)HAL_SPI_TransmitReceive(&hspi1, tx, rx, 4, 10);
    HAL_GPIO_WritePin(IMU_CS_GPIO_Port, IMU_CS_Pin, GPIO_PIN_SET);
    SPI1_FlushRxFifo();
    return (uint16_t)(rx[2] | (rx[3] << 8));
}

static void BMI323_WriteReg(uint8_t reg, uint16_t val)
{
    uint8_t tx[4] = {
        reg & 0x7F,
        (uint8_t)(val & 0xFF),
        (uint8_t)((val >> 8) & 0xFF),
        0x00,
    };
    uint8_t rx[4] = {0};
    SPI1_FlushRxFifo();
    HAL_GPIO_WritePin(IMU_CS_GPIO_Port, IMU_CS_Pin, GPIO_PIN_RESET);
    (void)HAL_SPI_TransmitReceive(&hspi1, tx, rx, 4, 10);
    HAL_GPIO_WritePin(IMU_CS_GPIO_Port, IMU_CS_Pin, GPIO_PIN_SET);
    SPI1_FlushRxFifo();
    BMI323_POST_WRITE_DELAY();
}

static void BMI323_BurstRead(uint8_t reg, int16_t *out, uint8_t count)
{
    uint8_t tx_len = 2 + (count * 2);
    uint8_t tx[14] = {0};
    uint8_t rx[14] = {0};
    tx[0] = reg | 0x80;
    SPI1_FlushRxFifo();
    HAL_GPIO_WritePin(IMU_CS_GPIO_Port, IMU_CS_Pin, GPIO_PIN_RESET);
    __NOP(); __NOP(); __NOP(); __NOP();
    (void)HAL_SPI_TransmitReceive(&hspi1, tx, rx, tx_len, 10);
    __NOP(); __NOP();
    HAL_GPIO_WritePin(IMU_CS_GPIO_Port, IMU_CS_Pin, GPIO_PIN_SET);
    SPI1_FlushRxFifo();
    for (uint8_t i = 0; i < count; i++) {
        uint8_t base = 2 + (i * 2);
        out[i] = (int16_t)(rx[base] | (rx[base + 1] << 8));
    }
}

static uint8_t BMI323_InitFeatureEngine(void)
{
    BMI323_WriteReg(BMI323_REG_FEATURE_IO0, 0x0000); HAL_Delay(1);
    BMI323_WriteReg(BMI323_REG_FEATURE_IO2, 0x012C); HAL_Delay(1);
    BMI323_WriteReg(BMI323_REG_FEATURE_IO_ST, 0x0001); HAL_Delay(1);
    BMI323_WriteReg(BMI323_REG_FEATURE_CTRL, 0x0001); HAL_Delay(10);
    for (int i = 0; i < 50; i++) {
        HAL_Delay(10);
        uint16_t status = BMI323_ReadReg(BMI323_REG_FEATURE_IO1);
        uint8_t err = status & 0x0F;
        if (err == 0x01) return 0;
        if (err == 0x03) return 1;
    }
    return 1;
}

static uint8_t BMI323_Init(void)
{
    HAL_Delay(10);
    uint8_t rst_tx[3] = {BMI323_REG_CMD & 0x7F, 0xAF, 0xDE};
    uint8_t rst_rx[3] = {0};
    SPI1_FlushRxFifo();
    HAL_GPIO_WritePin(IMU_CS_GPIO_Port, IMU_CS_Pin, GPIO_PIN_RESET);
    (void)HAL_SPI_TransmitReceive(&hspi1, rst_tx, rst_rx, 3, 10);
    HAL_GPIO_WritePin(IMU_CS_GPIO_Port, IMU_CS_Pin, GPIO_PIN_SET);
    HAL_Delay(50);
    HAL_SPI_DeInit(&hspi1);
    HAL_Delay(1);
    MX_SPI1_Init();
    HAL_Delay(1);
    BMI323_ReadReg(BMI323_REG_CHIP_ID); HAL_Delay(50);
    BMI323_ReadReg(BMI323_REG_CHIP_ID); HAL_Delay(10);
    who_am_i_result = BMI323_ReadReg(BMI323_REG_CHIP_ID);
    if ((who_am_i_result & 0x00FF) != 0x43) return 1;
    acc_conf_default = BMI323_ReadReg(BMI323_REG_ACC_CONF);
    if (BMI323_InitFeatureEngine() != 0) return 2;
    BMI323_WriteReg(BMI323_REG_ACC_CONF, BMI323_ACC_CONF_VAL); HAL_Delay(10);
    acc_conf_readback = BMI323_ReadReg(BMI323_REG_ACC_CONF);
    BMI323_WriteReg(BMI323_REG_GYR_CONF, BMI323_GYR_CONF_VAL); HAL_Delay(10);
    gyr_conf_readback = BMI323_ReadReg(BMI323_REG_GYR_CONF);
    return 0;
}

static void BMI323_ReadAccel(void)
{
    int16_t buf[3];
    BMI323_BurstRead(BMI323_REG_ACC_DATA, buf, 3);
    imu_acc_x = buf[0];
    imu_acc_y = buf[1];
    imu_acc_z = buf[2];
}

static void BMI323_ReadGyro(void)
{
    int16_t buf[3];
    BMI323_BurstRead(BMI323_REG_GYR_DATA, buf, 3);
    imu_gyr_x = buf[0];
    imu_gyr_y = buf[1];
    imu_gyr_z = buf[2];
}

/* USER CODE END 0 */

/**
  * @brief  The application entry point.
  * @retval int
  */
int main(void)
{

  /* MPU Configuration--------------------------------------------------------*/
  MPU_Config();

  /* MCU Configuration--------------------------------------------------------*/

  /* Reset of all peripherals, Initializes the Flash interface and the Systick. */
  HAL_Init();

  /* Configure the system clock */
  SystemClock_Config();

  /* Initialize all configured peripherals */
  MX_GPIO_Init();
  MX_DMA_Init();
  MX_USART1_UART_Init();
  MX_SPI1_Init();
  MX_TIM4_Init();
  MX_I2C1_Init();
  MX_USART2_UART_Init();
  MX_TIM6_Init();
  MX_USART3_UART_Init();
  MX_FATFS_Init();
  /* USER CODE BEGIN 2 */

    char msg[128];
    uint32_t loop_count = 0;

    HAL_Delay(10);

    DSHOT_Init();
    UART_Print("[DSHOT] driver ready\r\n");

    HAL_TIM_Base_Start_IT(&htim6);
    UART_Print("[DSHOT] 1kHz timer started\r\n");

    snprintf(msg, sizeof(msg), "[DSHOT] arming loop start t=%lums\r\n",
             HAL_GetTick());
    UART_Print(msg);

    for (int i = 0; i < 800; i++) {
        HAL_Delay(10);
    }

    snprintf(msg, sizeof(msg), "[DSHOT] arming loop done  t=%lums\r\n",
             HAL_GetTick());
    UART_Print(msg);
    UART_Print("[DSHOT] ESCs armed\r\n");

    UART_Print("[FLARE] boot ok\r\n");

    uint8_t init_result = BMI323_Init();
    if (init_result == 1) {
        UART_Print("[IMU] INIT FAILED -- WHO_AM_I mismatch\r\n");
        Error_Handler();
    } else if (init_result == 2) {
        UART_Print("[IMU] INIT FAILED -- feature engine timeout\r\n");
        Error_Handler();
    }

    snprintf(msg, sizeof(msg), "[IMU] WHO_AM_I    = 0x%02X (expect 0x43)\r\n",
             who_am_i_result & 0x00FF);
    UART_Print(msg);
    snprintf(msg, sizeof(msg), "[IMU] ACC default = 0x%04X\r\n",
             acc_conf_default);
    UART_Print(msg);
    snprintf(msg, sizeof(msg), "[IMU] ACC write   = 0x%04X (expect 0x4028)\r\n",
             acc_conf_readback);
    UART_Print(msg);
    snprintf(msg, sizeof(msg), "[IMU] GYR write   = 0x%04X (expect 0x4048)\r\n",
             gyr_conf_readback);
    UART_Print(msg);

    IMU_Fusion_Init(&imu_fusion, 0.01f, 80.0f, 30.0f);
    UART_Print("[FUSION] complementary filter + LPF ready\r\n");

    mag_cal.offset_x = -251.0f;
    mag_cal.offset_y = 41.5f;
    uint8_t mag_chip_id = 0;
    uint8_t mag_result = MAG_Init(&hi2c1, &mag_chip_id);
    uint8_t mag_ok = (mag_result != MAG_ERR_I2C);
    snprintf(msg, sizeof(msg), "[MAG] chip ID = 0x%02X\r\n", mag_chip_id);
    UART_Print(msg);
    if (!mag_ok) {
        UART_Print("[MAG] INIT FAILED -- skipping mag reads\r\n");
    } else {
        UART_Print("[MAG] QMC5883P ready\r\n");
    }

    FLARE_Init();
    UART_Print("[FLARE] PID controller ready\r\n");

    RC_Init();
    snprintf(msg, sizeof(msg), "[RC] init status=%u (0=OK)\r\n", rc_init_status);
    UART_Print(msg);
    UART_Print("[RC] USART2 receiver ready\r\n");

    /* ── GPS init ───────────────────────────────────────────────────────── */
    GPS_Init(&huart3, &gps_data);
    UART_Print("[GPS] USART3 DMA receiver ready\r\n");
    UART_Print("[GPS] waiting for fix (may take 30-120s outdoors)...\r\n");

    /* ── IMU level calibration ───────────────────────────────────────────── *
     * Runs for IMU_CAL_SAMPLES * 10ms (5 seconds). The first IMU_CAL_SETTLE  *
     * samples are discarded to let the complementary filter converge; the     *
     * final IMU_CAL_AVG_COUNT samples (1 second) are averaged for the offset. *
     *                                                                          *
     * If either offset exceeds IMU_CAL_MAX_OFFSET_DEG the quad is not level   *
     * — print a warning and halt rather than fly with a bad calibration.       *
     * ───────────────────────────────────────────────────────────────────────*/
    UART_Print("[CAL] Hold still — levelling IMU (5s)...\r\n");
    float imu_roll_offset  = 0.0f;
    float imu_pitch_offset = 0.0f;
    float cal_roll_sum  = 0.0f;
    float cal_pitch_sum = 0.0f;
    for (int cal_i = 0; cal_i < IMU_CAL_SAMPLES; cal_i++) {
        BMI323_ReadAccel();
        BMI323_ReadGyro();
        IMU_Fusion_Update(&imu_fusion,
                          imu_acc_x, imu_acc_y, imu_acc_z,
                          imu_gyr_x, imu_gyr_y, imu_gyr_z,
                          0.0f, 0.01f, 0.96f, 0.90f);
        if (cal_i >= IMU_CAL_SETTLE) {
            cal_roll_sum  += imu_fusion.roll;
            cal_pitch_sum += imu_fusion.pitch;
        }
        HAL_Delay(10);
    }
    imu_roll_offset  = cal_roll_sum  / (float)IMU_CAL_AVG_COUNT;
    imu_pitch_offset = cal_pitch_sum / (float)IMU_CAL_AVG_COUNT;
    snprintf(msg, sizeof(msg), "[CAL] level offset: roll=%.2f  pitch=%.2f\r\n",
             imu_roll_offset, imu_pitch_offset);
    UART_Print(msg);

    /* Sanity check — offsets beyond ±10° mean the quad wasn't level */
    if (imu_roll_offset  >  IMU_CAL_MAX_OFFSET_DEG ||
        imu_roll_offset  < -IMU_CAL_MAX_OFFSET_DEG ||
        imu_pitch_offset >  IMU_CAL_MAX_OFFSET_DEG ||
        imu_pitch_offset < -IMU_CAL_MAX_OFFSET_DEG) {
        UART_Print("[CAL] ERROR -- offset exceeds ±10 deg, quad not level -- HALTING\r\n");
        Error_Handler();
    }
    UART_Print("[CAL] offsets OK\r\n");

    UART_Print("[IMU] starting 100Hz loop\r\n");

    /* ── SD card blackbox logger init ───────────────────────────────────── */
    SD_Log_Result_t sd_log_result = SD_Log_Init();
    UART_Print(SD_Log_StatusStr());
    UART_Print("\r\n");
    if (sd_log_result != SD_LOG_OK) {
        UART_Print("[SD] WARNING: logging disabled\r\n");
    }

    /* SD init disturbs SPI1 — reinitialize BMI323 to restore its config */
    if (BMI323_Init() == 0) {
        UART_Print("[IMU] post-SD reinit OK\r\n");
    } else {
        UART_Print("[IMU] post-SD reinit FAILED\r\n");
        Error_Handler();
    }

  /* USER CODE END 2 */

  /* Infinite loop */
  /* USER CODE BEGIN WHILE */
    while (1)
    {
    /* USER CODE END WHILE */

    /* USER CODE BEGIN 3 */

        uint32_t tick_start = HAL_GetTick();

        /* Flush SPI1 RX FIFO before every IMU read — prevents residual bytes
         * from prior SD transactions corrupting the first BMI323 burst read. */
        SPI1_FlushRxFifo();

        BMI323_ReadAccel();
        BMI323_ReadGyro();

        /* Dropout guard — all-zero accel is physically impossible in normal
         * operation and indicates a corrupted SPI read caused by SD bus
         * contention. Replace with last known-good sample so the fusion
         * filter receives a continuous valid signal. */
        if (imu_acc_x == 0 && imu_acc_y == 0 && imu_acc_z == 0) {
            imu_acc_x = last_acc_x;
            imu_acc_y = last_acc_y;
            imu_acc_z = last_acc_z;
        } else {
            last_acc_x = imu_acc_x;
            last_acc_y = imu_acc_y;
            last_acc_z = imu_acc_z;
        }

        if (mag_ok) {
            int16_t mag_rx, mag_ry, mag_rz;
            if (MAG_ReadRaw(&hi2c1, &mag_rx, &mag_ry, &mag_rz) == MAG_OK) {
                float cx = (float)mag_rx - mag_cal.offset_x;
                float cy = (float)mag_ry - mag_cal.offset_y;
                float h = atan2f(cy, cx) * (180.0f / (float)M_PI);
                if (h < 0.0f) h += 360.0f;
                mag_heading = h;
            }
        }

        IMU_Fusion_Update(&imu_fusion,
                          imu_acc_x, imu_acc_y, imu_acc_z,
                          imu_gyr_x, imu_gyr_y, imu_gyr_z,
                          mag_heading, 0.01f, 0.96f, 0.90f);

        float roll_corr  = imu_fusion.roll  - imu_roll_offset;
        float pitch_corr = imu_fusion.pitch - imu_pitch_offset;

        /* ── GPS tick ───────────────────────────────────────────────────── */
        GPS_Update(&gps_data);

        /* ── RC packet consumption ──────────────────────────────────────── */
        if (RC_GetPacket(&rc_pkt)) {
            snprintf(msg, sizeof(msg),
                     "[RC] arm=%u thr=%u rol=%u pit=%u yaw=%u mode=%u crc_fail=%lu\r\n",
                     rc_pkt.armed,
                     rc_pkt.throttle, rc_pkt.roll,
                     rc_pkt.pitch,    rc_pkt.yaw,
                     rc_pkt.mode,
                     rc_crc_failures);
            UART_Print(msg);
        }

        if (RC_IsHealthy() && rc_pkt.mode != FLARE_MODE_SAFE) {
            motors_enabled = 1;

            FLARE_SetRollSP   (((float)rc_pkt.roll    - 1500.0f) * (30.0f  / 500.0f));
            FLARE_SetPitchSP  (((float)rc_pkt.pitch   - 1500.0f) * (30.0f  / 500.0f));
            FLARE_SetYawRateSP(((float)rc_pkt.yaw     - 1500.0f) * (200.0f / 500.0f));

            uint16_t dshot_thr = (uint16_t)(
                ((float)(rc_pkt.throttle - 1000) / 1000.0f)
                * (2047.0f - 48.0f) + 48.0f);
            if (dshot_thr < 48) dshot_thr = 48;

            FLARE_SetThrottle(dshot_thr);
            FLARE_SetArmed(1);
            FLARE_Update(roll_corr, pitch_corr,
                         imu_fusion.gx_dps, imu_fusion.gy_dps, imu_fusion.gz_dps,
                         0.01f);

            snprintf(msg, sizeof(msg),
                     "[THR] rc=%u dshot=%u m1=%u m2=%u m3=%u m4=%u\r\n",
                     rc_pkt.throttle, dshot_thr,
                     dshot_m1, dshot_m2, dshot_m3, dshot_m4);
            UART_Print(msg);
        } else {
            motors_enabled = 0;
            FLARE_SetArmed(0);
            FLARE_SetThrottle(0);
            FLARE_Update(roll_corr, pitch_corr,
                         imu_fusion.gx_dps, imu_fusion.gy_dps, imu_fusion.gz_dps,
                         0.0f);

            snprintf(msg, sizeof(msg),
                     "[SAFE] m1=%u m2=%u m3=%u m4=%u\r\n",
                     dshot_m1, dshot_m2, dshot_m3, dshot_m4);
            UART_Print(msg);
        }

        snprintf(msg, sizeof(msg),
                 "A:%6d %6d %6d  G:%6d %6d %6d"
                 "  R:%7.2f  P:%7.2f  Y:%7.2f  RC:%s\r\n",
                 imu_acc_x, imu_acc_y, imu_acc_z,
                 imu_gyr_x, imu_gyr_y, imu_gyr_z,
                 roll_corr, pitch_corr, imu_fusion.yaw,
                 RC_IsHealthy() ? "OK" : "LOST");
        UART_Print(msg);

        /* ── GPS telemetry print (once per second = every 100 loops) ────── */
        if (loop_count % 100 == 0) {
            snprintf(msg, sizeof(msg),
                     "[GPS] fix=%u sats=%u lat=%.6f lon=%.6f alt=%.1fft spd=%.1fmph\r\n",
                     gps_data.fix_valid,
                     gps_data.satellites,
                     (double)gps_data.latitude,
                     (double)gps_data.longitude,
                     (double)gps_data.altitude_ft,
                     (double)gps_data.speed_mph);
            UART_Print(msg);

            snprintf(msg, sizeof(msg),
                     "[DIAG] send=%lu tc=%lu\r\n",
                     dshot_send_count, dshot_tc_count);
            UART_Print(msg);
        }

        ++loop_count;

        /* Deadline-based delay — sleep only the remaining time in this 10ms
         * tick. Prevents long operations from pushing the next IMU read late. */
        uint32_t elapsed = HAL_GetTick() - tick_start;
        if (elapsed < IMU_LOOP_INTERVAL_MS) {
            HAL_Delay(IMU_LOOP_INTERVAL_MS - elapsed);
        }

        /* ── SD operations AFTER delay — maximally far from next IMU read ──
         * SPI1_FlushRxFifo() after each call ensures the bus is clean before
         * the next tick's BMI323_ReadAccel(). */
        if (loop_count % 20 == 0) {
            SD_Log_Write(
                HAL_GetTick(),
                roll_corr, pitch_corr, imu_fusion.yaw,
                imu_acc_x, imu_acc_y, imu_acc_z,
                imu_gyr_x, imu_gyr_y, imu_gyr_z,
                rc_pkt.throttle,
                dshot_m1, dshot_m2, dshot_m3, dshot_m4,
                rc_pkt.armed,
                RC_IsHealthy(),
                gps_data.fix_valid,
                gps_data.satellites,
                gps_data.latitude,
                gps_data.longitude,
                gps_data.altitude_ft,
                gps_data.speed_mph
            );
            SPI1_FlushRxFifo();
        }

        if (loop_count % 100 == 1) {
            SD_Log_Flush();
            SPI1_FlushRxFifo();
        }

    /* USER CODE END 3 */
    }   /* end while(1) */
}       /* end main()   */

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
/* USER CODE BEGIN 4 */

void HAL_UART_RxCpltCallback(UART_HandleTypeDef *huart)
{
    if (huart->Instance == USART2) {
        RC_UART_RxCpltCallback();
    }
}

/* USER CODE END 4 */

static void MPU_Config(void)
{
    MPU_Region_InitTypeDef MPU_InitStruct = {0};

    HAL_MPU_Disable();

    /*
     * Region 0: AXI SRAM (0x24000000, 512KB) — Non-cacheable.
     *
     * The DSHOT DMA buffer lives here. Non-cacheable ensures CPU writes
     * are immediately visible to DMA without explicit cache flush calls.
     * TEX=1, C=0, B=0 = Normal memory, Non-cacheable.
     */
    MPU_InitStruct.Enable             = MPU_REGION_ENABLE;
    MPU_InitStruct.Number             = MPU_REGION_NUMBER0;
    MPU_InitStruct.BaseAddress        = 0x24000000;
    MPU_InitStruct.Size               = MPU_REGION_SIZE_512KB;
    MPU_InitStruct.SubRegionDisable   = 0x00;
    MPU_InitStruct.TypeExtField       = MPU_TEX_LEVEL1;
    MPU_InitStruct.AccessPermission   = MPU_REGION_FULL_ACCESS;
    MPU_InitStruct.DisableExec        = MPU_INSTRUCTION_ACCESS_DISABLE;
    MPU_InitStruct.IsShareable        = MPU_ACCESS_NOT_SHAREABLE;
    MPU_InitStruct.IsCacheable        = MPU_ACCESS_NOT_CACHEABLE;
    MPU_InitStruct.IsBufferable       = MPU_ACCESS_NOT_BUFFERABLE;
    HAL_MPU_ConfigRegion(&MPU_InitStruct);

    HAL_MPU_Enable(MPU_PRIVILEGED_DEFAULT);
}

void Error_Handler(void)
{
  /* USER CODE BEGIN Error_Handler_Debug */
    __disable_irq();
    while (1) {}
  /* USER CODE END Error_Handler_Debug */
}

#ifdef USE_FULL_ASSERT
void assert_failed(uint8_t *file, uint32_t line)
{
}
#endif /* USE_FULL_ASSERT */

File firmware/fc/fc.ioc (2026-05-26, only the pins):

Mcu.UserName=STM32H723ZGTx
PA10.Signal=USART1_RX
PA2.Signal=USART2_TX
PA3.Signal=USART2_RX
PA5.Signal=SPI1_SCK
PA6.Signal=SPI1_MISO
PA7.Signal=SPI1_MOSI
PA9.Signal=USART1_TX
PB0.GPIO_Label=IMU_CS
PB0.Signal=GPIO_Output
PB1.GPIO_Label=IMU_INT1
PB1.Signal=GPIO_Input
PB10.Signal=USART3_TX
PB11.Signal=USART3_RX
PB6.Signal=I2C1_SCL
PB7.Signal=I2C1_SDA
PC0.GPIO_Label=SD_CS
PC0.Signal=GPIO_Output
PD12.Signal=S_TIM4_CH1
PD13.Signal=S_TIM4_CH2
PD14.Signal=S_TIM4_CH3
PD15.Signal=S_TIM4_CH4
PG7.GPIO_Label=LED_USER
PG7.Signal=GPIO_Output

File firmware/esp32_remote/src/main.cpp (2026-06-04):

// =============================================================================
// FLARE — esp32_remote
// ESP-NOW transmitter: reads sticks + switches, sends FLARE_RC_Packet_t
// to the quad-side ESP32 at 50Hz.
//
// UART wiring (Nano ESP32 → FK723M1, for future telemetry RX):
//   GPIO17 (TX, D4) → STM32 RX
//   GPIO18 (RX, D5) → STM32 TX  (unused in Phase 5, reserved)
//   GND             → GND
//
// Display states:
//   SPLASH  → shown for SPLASH_DURATION_MS on power-on
//   IDLE    → shown while disarmed (mode == SAFE)
//   FLYING  → shown while armed (mode == ANGLE or ACRO)
// =============================================================================

#include <Arduino.h>
#include <U8g2lib.h>
#include <WiFi.h>
#include <esp_now.h>

#include "flare_protocol.h"

// ---------------------------------------------------------------------------
// Target peer — quad-side ESP32 MAC address
// ---------------------------------------------------------------------------
static const uint8_t kQuadMac[6] = {0xD4, 0xE9, 0xF4, 0xE6, 0xE9, 0x90};

// ---------------------------------------------------------------------------
// Pin assignments — sticks and switches
//
// Both gimbals are mounted 90° rotated from their default orientation.
// Pin assignments are swapped here at the source to compensate, so all
// downstream code (packet fields, STM32 mapping) remains semantically correct.
//
//   Left gimbal:  throttle ← X-axis (A1), yaw ← Y-axis (A0)
//   Right gimbal: roll     ← Y-axis (A2), pitch ← X-axis (A3)
// ---------------------------------------------------------------------------
#define PIN_THROTTLE A1  // left gimbal X-axis  (was A0 pre-rotation)
#define PIN_YAW A0       // left gimbal Y-axis  (was A1 pre-rotation)
#define PIN_PITCH A3     // right gimbal X-axis (was A2 pre-rotation)
#define PIN_ROLL A2      // right gimbal Y-axis (was A3 pre-rotation)

#define PIN_MODE_SWITCH_A D3  // mode switch terminal 1 (UP)   — LOW = ANGLE
#define PIN_MODE_SWITCH_B D4  // mode switch terminal 3 (DOWN) — LOW = ACRO
//
// Mode switch truth table:
//   D3=LOW,  D4=HIGH → FLARE_MODE_ANGLE (UP position)
//   D3=HIGH, D4=HIGH → FLARE_MODE_SAFE  (CENTER — forces disarm on FC)
//   D3=HIGH, D4=LOW  → FLARE_MODE_ACRO  (DOWN position)

// ---------------------------------------------------------------------------
// OLED — HiLetgo 2.42" SSD1309 SPI
// ---------------------------------------------------------------------------
#define PIN_OLED_CS D10
#define PIN_OLED_DC D6
#define PIN_OLED_RST D7

static U8G2_SSD1309_128X64_NONAME0_F_4W_HW_SPI u8g2(U8G2_R0, PIN_OLED_CS,
                                                    PIN_OLED_DC, PIN_OLED_RST);

// ---------------------------------------------------------------------------
// Timing
// ---------------------------------------------------------------------------
#define TX_RATE_HZ 50
#define TX_INTERVAL_MS (1000 / TX_RATE_HZ)  // 20ms
#define DISP_INTERVAL_MS 100                // 10Hz display refresh
#define SPLASH_DURATION_MS 2000             // 2s splash on boot

// ---------------------------------------------------------------------------
// ADC calibration — per axis, measured on hardware
// ---------------------------------------------------------------------------
struct AxisCal {
    uint16_t min;
    uint16_t center;
    uint16_t max;
    uint16_t deadband;
    bool reversed;
};

static const AxisCal kThrottle = {326, 0, 3869, 0, false};
static const AxisCal kYaw = {253, 1949, 3418, 60, false};
static const AxisCal kPitch = {38, 1803, 3129, 40, false};
static const AxisCal kRoll = {251, 1623, 3647, 40, false};

// ---------------------------------------------------------------------------
// Diagnostics
// ---------------------------------------------------------------------------
static uint32_t packets_sent = 0;
static uint32_t packets_failed = 0;

// Last sent packet — read by display update
static FLARE_RC_Packet_t last_pkt = {};

// ---------------------------------------------------------------------------
// Display state machine
// ---------------------------------------------------------------------------
enum DisplayState { DISP_SPLASH, DISP_IDLE, DISP_FLYING };

static DisplayState disp_state = DISP_SPLASH;
static uint32_t splash_start = 0;

// ---------------------------------------------------------------------------
// Telemetry placeholders — replaced by real downlink values in future
// ---------------------------------------------------------------------------
static uint8_t telem_sats = 0;
static uint16_t telem_heading = 0;  // degrees
static int32_t telem_alt_dm = 0;    // decimetres (alt_m * 10)
static uint16_t telem_spd_cms = 0;  // cm/s      (spd_ms * 100)

// ---------------------------------------------------------------------------
// ESP-NOW send callback
// ---------------------------------------------------------------------------
static void on_packet_sent(const uint8_t* mac_addr,
                           esp_now_send_status_t status) {
    (void)mac_addr;
    if (status == ESP_NOW_SEND_SUCCESS)
        packets_sent++;
    else
        packets_failed++;
}

// ---------------------------------------------------------------------------
// map_stick()
// ---------------------------------------------------------------------------
static uint16_t map_stick(uint16_t raw, const AxisCal& cal) {
    raw = constrain(raw, cal.min, cal.max);

    uint16_t mapped;

    if (cal.center == 0) {
        mapped =
            (uint16_t)map(raw, cal.min, cal.max, FLARE_CH_MIN, FLARE_CH_MAX);
    } else {
        if (abs((int)raw - (int)cal.center) < (int)cal.deadband) {
            raw = cal.center;
        }
        if (raw <= cal.center) {
            mapped = (uint16_t)map(raw, cal.min, cal.center, FLARE_CH_MIN,
                                   FLARE_CH_MID);
        } else {
            mapped = (uint16_t)map(raw, cal.center, cal.max, FLARE_CH_MID,
                                   FLARE_CH_MAX);
        }
    }

    mapped = constrain(mapped, FLARE_CH_MIN, FLARE_CH_MAX);
    if (cal.reversed) mapped = FLARE_CH_MIN + FLARE_CH_MAX - mapped;
    return mapped;
}

// ---------------------------------------------------------------------------
// read_mode() / read_mode_debounced()
// ---------------------------------------------------------------------------
static uint8_t read_mode() {
    bool a = (digitalRead(PIN_MODE_SWITCH_A) == LOW);
    bool b = (digitalRead(PIN_MODE_SWITCH_B) == LOW);
    if (a) return FLARE_MODE_ANGLE;
    if (b) return FLARE_MODE_ACRO;
    return FLARE_MODE_SAFE;
}

#define DEBOUNCE_MS 20
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

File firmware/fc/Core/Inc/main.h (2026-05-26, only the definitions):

#define SD_CS_Pin GPIO_PIN_0
#define SD_CS_GPIO_Port GPIOC
#define IMU_CS_Pin GPIO_PIN_0
#define IMU_CS_GPIO_Port GPIOB
#define IMU_INT1_Pin GPIO_PIN_1
#define IMU_INT1_GPIO_Port GPIOB
#define LED_USER_Pin GPIO_PIN_7
#define LED_USER_GPIO_Port GPIOG

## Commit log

2026-04-07 chore: initial project scaffold and Phase 1 FC bring-up
    - Add monorepo structure (firmware/fc, esp32_quad, esp32_remote)
    - Add CubeMX CMake project for STM32H723ZGT6 (FK723M1-ZGT6 board)
    - Configure HSE PLL1 550MHz SYSCLK, 275MHz HCLK
    - Configure PA0 GPIO output (LED blink) and USART1 PA9/PA10 at 115200
    - Add Phase 1 blink + UART hello world in main.c
    - Add ESP32 quad and remote PlatformIO stubs (Phase 4/5 targets)
    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
2026-04-09 feat(fc): verify Phase 1 UART output on hardware (STM32H723)
2026-04-09 fix(fc): correct user LED pin to PG7, fix USER CODE marker placement
    feat(fc): verify Phase 1 blink on hardware (STM32H723, PG7 blue LED)
    [fc.ioc, main.c, main.h]
2026-04-12 docs(hardware-notes): replace ICM-42688-P with BMI323, add SPI wiring notes
2026-04-12 docs(readme): update IMU from ICM-42688-P to BMI323
2026-04-13 docs(hardware-notes): replace ICM-42688-P with BMI323, and SPI wiring notes
2026-04-14 fix(fc/main): fix missing closing brace on main(), restore string.h include after CubeMX regen
    [fc.ioc, main.c, main.h]
2026-04-14 feat(fc/imu): add BMI323 WHO_AM_I read via SPI on boot
2026-04-14 feat(fc/imu): switch debug output to ITM SWO, add BMI323 WHO_AM_I read
2026-04-14 feat(fc/imu): confirm BMI323 WHO_AM_I = 0x0043 via SPI, promote result to global for RAM inspection
2026-04-14 docs: update hardware-notes with confirmed BMI323 SPI wiring, update README phase status
2026-04-15 feat(fc/imu): add BMI323 init, burst accel/gyro read at 100Hz
2026-04-15 fix(fc/imu): fix STM32H7 SPI protocol bugs - NSSP, byte order, write path
    [main.c]
2026-04-18 fix(fc/imu): fix BMI323 SPI write - pad to 4 bytes, add feature engine init, recover SPI post-reset
    [main.c]
2026-04-18 docs: update all docs for Phase 2 IMU bring-up completion
2026-04-18 test(fc/imu): verify BMI323 accel axis response on physical tilt
2026-04-19 feat(fc/fusion): add complementary filter for roll/pitch estimation
2026-04-19 feat(fc/dshot): add DSHOT300 driver - TIM4 PWM + DMA burst, ESC arming
2026-04-19 feat(fc/esc): wire and verify ESC signal lines - DSHOT arming confirmed
2026-04-19 feat(fc/pid): add PID controller and FLARE flight controller loop
2026-04-19 fix(fc/pid): convert raw gyro LSB to dps before PID derivative term
    [main.c]
2026-04-19 fix(fc/flare): move FLARE_SetArmed and FLARE_SetThrottle to file scope
    [flare.c, main.c]
2026-04-20 fix(fc/dshot): fix DMA buffer placement (D1 SRAM), frame timing, and arming sequence
    [dshot.c, fc.ioc, main.c]
2026-04-20 fix(fc/dshot): set DMABusrt transfer length to full frame (68 words)
    [dshot.c]
2026-04-20 feat(fc/mag): add QMC5883L magnetometer driver and yaw fusion
2026-04-21 ci: add GitHub Actions workflow for STM32 firmware build with warnings-as-errors
2026-04-21 fix(ci): install libnewlib-arm-none-eabi to provide math.h on Ubuntu runner
2026-04-21 chore: silence clangd diagnostics for ESP32 PlatformIO projects
    Add .clangd with suppressed diagnostics for esp32_quad and esp32_remote.
    Microsoft C++ engine reads PlatformIO's c_cpp_properties.json for
    IntelliSense; clangd is intentionally muted to avoid false positives.
2026-04-21 feat(esp32_quad): add ESP-NOW receiver and UART bridge to STM32
2026-04-21 fix(esp32_quad): use ESP-NOW recv callback signature compatible with Arduino core 2.x
    [main.cpp]
2026-04-22 chore(config): add BLHeli_S ESC setup backup
2026-04-23 fix(fc/dshot): replace HAL DMA burst API with direct DMA register programming
    [dshot.c]
2026-04-23 fix(fc/dshot): set CCR1-4 idle-high on DMA transfer complete via TC interrupt
2026-04-23 fix(fc/main): send zero throttle each loop iteration to keep ESCs armed
    chore(fc/main): remove bench test, motors confirmed spinning on all 4 channels
    fix(fc): add MPU region for AXI SRAM DMA buffer at 0x24000000
    [main.c]
2026-04-23 feat(fc): enable USART2 on PA2/PA3 for ESP32 RC link
2026-04-23 feat(fc/rc): add USART2 interrupt-driven RC receiver (rc.c, rc.h)
2026-04-23 feat(fc/main): integrate RC receiver, restore MPU Region 1, fix shared include path
    [main.c]
2026-04-23 fix(fc/dshot): wait for DMA stream disable instead of force-aborting transfer on re-arm
    [dshot.c]
2026-04-23 fix(fc/mag): gate mag reads behind mag_ok, remove Error_Handler on mag fail
    [mag.c]
2026-04-23 fix(fc/usart): set USART2 IRQ priority to 8,0 below DSHOT DMA
2026-04-23 fix(fc/main): gate mag reads behind mag_ok, remove Error_Handler on mag fail
    [main.c]
2026-04-24 fix(esp32_quad): correct shared header path in extra_script.py (one level up, not two)
2026-04-24 fix(esp32_remote): add extra_script.py for shared header path resolution
2026-04-24 feat(esp32_remote): implement ESP-NOW transmitter at 50Hz with stick/switch stubs
2026-04-24 chore(hardware): add frame directory with CAD and STL files, add .gitattributes for binary formats
    [2605-36477_MDL_arm.dwg, 2605-36477_MDL_arm.stl, 2605-36477_MDL_bottom-mount.dwg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]
2026-04-25 feat(esp32_remote): add SSD1309 OLED display via U8g2, show arm/mode/throttle/TX status
2026-04-25 test(esp32_quad): verify ESP-NOW link at 50Hz - rx_ok incrementing, rx_bad=0
2026-04-25 feat(esp32_remote): integrate per-axis ADC calibration, update map_stick()
    test(esp32_remote): arcdhive gimbal ADC calibration sketch as adc_gimbal_test.cpp
2026-04-26 feat(esp32_remote): add ON/OFF/ON mode switch on D3/D4, arm switch on D12
2026-04-26 feat(fc): disarm on FLARE_MODE_SAFE - center mode switch forces disarm
2026-04-28 fix(esp32_quad): use Serial1 with explicit GPIO17/18 (A0/A1) for STM32 UART
    [main.cpp]
2026-04-28 fix(fc): clear USART2 error flags via ICR not ISR, zero-init rc_pkt in main loop
    [fc.ioc, main.c, rc.c]
2026-04-29 fix(all): update quad MAC, fix USART2 RDR read order, add MAC print to quad
    [main.c, main.cpp]
2026-04-29 docs: update hardware-notes with correct A0 TX pin config
2026-04-29 fix(fc): port mag driver from QMC5883L to QMC5883P, update MAG ready log message to QMC5883P
    [mag.c, main.c]
2026-04-29 docs: update mag hardware notes for QMC5883P register map
    Document confirmed QMC5883P chip (not QMC5883L) with correct
    register map, chip ID (0x80 at 0x00), CTRL layout, absence of
    FBR register, and verified I2C address 0x2C. Add warning about
    GY-271 module mislabelling. Update General Notes to reference
    QMC5883P and add loose connection troubleshooting note.
2026-04-29 fix(fc): connect PID output to DSHOT via RC packet, add FLARE setpoint setters
    Map RC channels [1000,2000] to roll/pitch (±30deg) and yaw rate
    (±200dps) setpoints each loop iteration. Add FLARE_SetRollSP,
    FLARE_SetPitchSP, FLARE_SetYawRateSP setters to keep FLARE_State
    encapsulated in flare.c. Remove redundant DSHOT_SendThrottle(0,0,0,0)
    from armed branch — FLARE_Update handles motor output directly.
    [flare.c, main.c]
2026-04-29 fix(esp32_remote): swap pin assignments for 90° gimbal mount orientation
    [main.cpp]
2026-04-30 fix(esp32_quad): migrate from Nano ESP32 (S3) to ESP32-WROOM-32
    Change board target: arduino_nano_esp32 → esp32dev
    Switch UART bridge to UART2 (GPIO17/16) via HardwareSerial(2)
    RX pin updated GPIO18 → GPIO16 (WROOM-32 RX2)
    Serial debug unchanged (CP2102 on UART0 = Serial)
    Add rx_rejected counter to on_packet_received
    [main.cpp]
2026-04-30 fix(esp32_remote): update quad MAC address for ESP32-WROOM-32 replacement
    Old MAC: 20:6E:F1:32:70:3C (Arduino Nano ESP32)
    New MAC: D4:E9:F4:E8:10:74 (ESP32-WROOM-32 CP2102)
    [main.cpp]
2026-05-04 fix(fc): replace DSHOT busy-wait with dshot_dma_busy flag, add TIM6 1kHz ISR
    [dshot.c, fc.ioc, flare.c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]
2026-05-05 refactor(fc/dshot): remove DMA timing diagnostics
    DMA transfer duration confirmed to be 0ms (completes within same TIM6 tick).
    DSHOT300 timing is not the cause of motor pulsing at low throttle.
    Removed diagnostic code as timing issue has been ruled out.
    [dshot.c, flare.c, main.c]
2026-05-08 fix(fc/esp32_remote/docs): Updated flight controller, update esp32_remote, added CLAUDE.md and SessionSummary.md
    [flare.c, main.c, main.cpp]
2026-05-15 fix(fc/dshot): correct idle state to LOW and Bluejay CRC
    Two bugs in the DSHOT300 driver caused all ESC communication to fail
    with Bluejay firmware:
    1. DSHOT_CCR_IDLE was ARR+1 (640), holding outputs idle-HIGH between
    frames. DSHOT requires idle-LOW — the ESC detects frame boundaries
    by seeing the line go LOW after the reset slot, then waiting for
    the next rising edge. Idle-HIGH prevented frame synchronisation,
    causing pulsing/galloping on BLHeli_S and complete silence on
    Bluejay. Fixed by setting DSHOT_CCR_IDLE = 0.
    2. CRC used inverted XOR (~(v ^ v>>4 ^ v>>8) & 0xF) per the DSHOT
    by seeing the line go LOW after the reset slot, then waiting for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
    [dshot.c]
2026-05-15 fix(fc/main): correct throttle mapping and add DSHOT diagnostics
    Throttle mapping was [1000,2000] → DSHOT [400,2047] clamped at 1000,
    so minimum stick always sent DSHOT 1000 (~50% throttle) on arm —
    dangerous snap-to-speed. Restored the correct mapping per CLAUDE.md:
    [1000,2000] → DSHOT [48,2047], clamp at 48. This restores the
    spool-up ramp in flare.c (throttle < 250 = equal throttle, no PID)
    and prevents spin-up jolt on arm.
    Added [DIAG] send/tc counters (printed once per second) to expose
    the TIM6 ISR fire count and DMA transfer-complete count, making it
    straightforward to confirm the DSHOT pipeline is alive without a
    scope.
    [main.c]
2026-05-15 fix(fc): update to integrate with known bugs of main.c/dshot.c/stm32h7xx_it.c
    [flare.c, main.cpp, rc.c]
2026-05-16 feat(fc/gps): add NEO-6M GPS driver on USART3 DMA
    NMEA parser targeting GPRMC and GPGGA sentences via circular DMA
    receive on USART3 (PB10/PB11, 9600 baud). GPS data struct populated
    at 5Hz with position, altitude (ft), speed (mph), course, fix status,
    and satellite count. DMA buffer placed in non-cacheable AXI SRAM
    (.AXI_SRAM section, RAM_D1). Printed once per second via [GPS] tag.
    Also adds USART2_IRQHandler to stm32h7xx_it.c for direct-register
    RC byte receive, resolving boot hang in RC_Init.
    [fc.ioc, gps.c, main.c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]
2026-05-16 docs: update hardware-notes and architecture for Phase 4.5 GPS
    Add GY-NEO6MV2 wiring, USART3 config, and .AXI_SRAM linker section
    to hardware-notes. Update architecture with GPS driver design,
    boot sequence, Bluejay CRC/idle-LOW constants, and Phase 4.5 status.
2026-05-24 feat(gps): replace NEO-6M NMEA parser with UBX binary for M100-5883
    - usart.c: USART3 baud 9600 → 115200 (M10 native rate)
    - gps.h: replace NMEA constants with UBX protocol defs; add fix_type
    and speed_ms fields to GPS_Data_t
    - gps.c: full rewrite — DMA ring buffer retained, NMEA parser replaced
    with UBX state machine parsing NAV-PVT (class 0x01, ID 0x07)
    [gps.c]
2026-05-24 fix(esp32_remote): update kQuadMac to match quad-side Nano MAC after reflash
    Flash corruption during STM32 programming changed the reported MAC from
    D4:E9:F4:E8:10:74 to D4:E9:F4:E6:E9:90. Updated kQuadMac accordingly.
    [main.cpp]
2026-05-26 feat(fc/sd): add SD_CS (PC0) GPIO for SPI micro-SD module
    - CubeMX: PC0 configured as GPIO_Output, idle HIGH, label SD_CS
    - gpio.c: GPIOC clock enabled; PC0 init added (GPIO_PIN_SET at boot)
    - main.h: SD_CS_Pin / SD_CS_GPIO_Port defines added
    - main.c: restore MPU_Config() after CubeMX clobbered custom AXI SRAM
    region (0x24000000, 512KB, non-cacheable) with generic 4GB template;
    restore main() and while(1) closing braces dropped by regeneration
2026-05-26 feat(fc/sd): add SPI micro-SD blackbox logger via FatFS
    - CubeMX: PC0 as GPIO_Output SD_CS, FatFS middleware enabled
    - FATFS/Target/user_diskio.c: full SPI diskio driver (SDHC/SDSC,
    CMD0/8/17/24/41/55/58, fixed /16 prescaler to avoid SPI bus
    conflicts with BMI323 on shared SPI1)
    - Core/Inc/sd.h, Core/Src/sd.c: logger layer — mount, LOGxxx.CSV
    auto-numbering, CSV header, 10Hz write, 1Hz f_sync flush
    - main.c: SD_Log_Init() + BMI323 reinit post-SD-init, SD_Log_Write()
    at 10Hz, SD_Log_Flush() at 1Hz
    - gpio.c: GPIOC clock enabled, PC0 init HIGH (SD_CS idle deselected)
    - cmake/stm32cubemx/CMakeLists.txt: FatFS sources already included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
    [main.c, main.h, sd.c]
2026-05-26 fix(fc/sd): remove debug prints, fix IMU single-sample dropout
    - user_diskio.c: remove all SD_DBG instrumentation added during bringup
    - SD_Deselect(): retain RX FIFO flush (SPE toggle) — HAL_SPI_Transmit
    leaves residual bytes in the FIFO that corrupt the first BMI323 read
    on the shared SPI1 bus after each SD transaction
2026-05-26 fix(fc/imu): suppress accel dropout caused by SD SPI bus contention
    - Add all-zero accel guard in main loop: physically impossible in normal
    operation, indicates corrupted SPI read from SD write stall bleeding
    into next BMI323 burst read on shared SPI1 bus
    - Replace dropout sample with last known-good accel values so fusion
    filter receives continuous valid signal
    - Reduce SD write rate from 10Hz to 5Hz to reduce erase block pressure
    - SD operations moved after HAL_Delay to maximize time between SD SPI
    transactions and next IMU read
    [mag.c, main.c]
2026-05-27 chore(tools): add FLARE blackbox log parser
    - Decodes integer-scaled CSV columns back to physical units
    - Computes mag hard-iron calibration offsets from spin log
    - Prints ready-to-paste offset_x / offset_y lines for main.c
2026-05-27 feat(fc/mag): hard-iron calibration complete; fix SD float logging
    - Apply mag hard-iron offsets: offest_x=-251.0, offset_y=41.5
    - Computed from 190-sample CW+CCW bench spin via tools/parse_log.py
    - Fix SD logger: replace %f with integer-scaled columns (f_printf has
    no float support in this FatFS build)
    - Remove temporary mag_x/mag_y calibration columns from SD log schema
    - Yaw holds stable heading on bench (~162-165deg stationary)
    [main.c, sd.c]
2026-06-01 fix(control): invert pitch and roll PID output signs in motor mixing.
    IMU pitch/roll polarity was inverted relative to mixing convention.
    Nose-down produced negative pitch causing PID to command positive
    out_pitch which increased front motors, amplifying the tilt.
    Negating both out_pitch and out_roll in the mixing formula corrects
    stabilization response on both axes. Verified via bench tilt test:
    quad now actively corrects toward level on all axes.
    Closes pitch/roll sign inversion bug identified.
    [flare.c]
2026-06-01 feat(esp32_quad): add MAC address output in serial
2026-06-01 tune(control): reduce P to 0.5, increase D to 0.10 on roll/pitch
    Second gain pass. kp 0.8→0.5, kd 0.08→0.10 on roll/pitch axes.
    Yaw kp 1.0→0.8. Bench tilt test shows gyro peaks reduced to
    ~350 deg/s on moderate tilts, steady-state settling within ±0.5°.
    System ready for tethered props-on test.
2026-06-03 fix(imu): apply IMU mounting offset correction in complementary filter
    Post-disarm analysis of LOG001 (t=80-88s, frame stationary) shows
    persistent roll=±0.27 deg, pitch=-3.80 deg resting biad. Offsets
    subtracted from accel-derived angles in IMU_Fusion_Update() so the
    complementary filter reference treats frame-level as 0/0.
    Bench-verified on level surface: steady-state roll<0.05 deg,
    pitch<0.02 deg. Offsets confirmed correct.
    [flare.c]
2026-06-03 tune(control): increase yaw kp and output limit for authority at hover
    LOG006 showed yaw PID saturating above ~43% throttle with out_limi=150.
    Increased out_limit to 300 to give correction headroom at high throttle.
    Increased kp from 0.8 to 1.2 for faster response to yaw rate onset.
    kd=0.05 unchanged. LOG007 confirmed improvement at 31-35% throttle.
    [flare.c]
2026-06-04 feat(imu/lpf): add first-order IIR LPF to gyro and accel pipeline
    New lpf.h/lpf.c: generic LPF_t with seeded cold-start guard,
    LPF_Update(), and LPF_ComputeAlpha(dt, fc_hz).
    IMU_Fusion_t embeds six LPF instances (gx/gy/gz at fc=80Hz,
    ax/ay/az at fc=30Hz, 100Hz loop rate). Filters applied post-unit-
    conversion, pre-atan2 and pre-gyro-integration.
    Filtered gyro rates exposed as imu_fusion.gx/gy/gz_dps. main.c
    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
2026-06-04 feat(flare): add throttle-proportional yaw feed-forward to motor mixing
    CCW motors (M1/M3) generate excess aerodynamic reaction torque above
    RC~1500, producing a persistent CW yaw spin the PID alone cannot arrest
    (confirmed across LOG010, LOG013, LOG014). Feed-forward applies a
    preemptive corrective differential proportional to throttle — boosting
    CW motors (M2/M4) and reducing CCW (M1/M3) before error develops.
    ff_gain=0.05f initial value. LOG018 confirmed FF working: peak gz
    reduced from -136 deg/s (LOG014) to -44 deg/s. Over-correction noted
    (CCW spin at thr>1425) — gain reduction applied in next commit.
    tune(flare): reduce yaw FF gain 0.05 -> 0.03 to correct over-correction
    LOG018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
    [flare.c]
2026-06-04 feat(remote): add 3-state OLED display (splash/idle/flying)
    - Splash screen on boot: FLARE / Flight Lab / v0.1.0 (2s)
    - Idle screen while disarmed: SAT, heading, ALT, battery placeholder
    - Flying screen while armed: full layout with SAT, heading, ALT,
    SPD, THR % + raw RC value, battery placeholder
    - Armed state driven by mode switch (ANGLE/ACRO = armed, SAFE = disarmed)
    - Telemetry fields (SAT/ALT/SPD/heading) stubbed as module-level
    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
2026-06-05 fix(imu/cal): extend boot-level calibration window 2s→5s, add sanity check
    IMU_CAL_SAMPLES=500 (5s), settling 4s, averaging final 1s (100 samples).
    Gives operator time to set the quad down and step back before the
    averaging window opens.
    Added ±10° sanity check on computed offsets - if exceeded, prints
    [CAL] ERROR and halts rather than flying with a bad calibration.
    Root cause of LOG000 lateral drift on liftoff.
    [main.c]
2026-06-05 fix(flare): revert yaw FF to linear (throttle-1000) scaling, restore ki_yaw
    Quadratic FF (LOG011) inverted CW-CCW differential and worsened spin to
    -789 deg/s mean at RC 1430-1470. Reverted to linear FF with (throttle-1000)
    offset so correction is zero at minimum throttle and scales from there.
    ki_yaw restored to 0.02f. ff_gain=0.030f. Pending ESC settings audit to
    diagnose RPM-threshold torque imbalance (~RC 1420) that no FF approach
    has resolved across LOG009-LOG012.
    [flare.c, main.c]
2026-06-06 fix(flare): remove FF, raise yaw int_limit to 150
    Removed feed-forward (ff_gain=0.0f) — FF was fighting the integrator
    across throttle bands without resolving the torque imbalance.
    Raised int_limit_yaw 30→150 to give integrator sufficient authority
    for static torque offset correction. ki_yaw remains 0.02f.
    Torque imbalance above RC~1420 confirmed hardware-bound; pending M1
    motor replacement and new props.
    [flare.c]

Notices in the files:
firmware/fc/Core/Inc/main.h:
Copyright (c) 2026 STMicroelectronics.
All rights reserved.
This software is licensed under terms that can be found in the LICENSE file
